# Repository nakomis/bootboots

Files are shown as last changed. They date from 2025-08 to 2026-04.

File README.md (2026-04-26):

# BootBoots - Autonomous Cat Territory Management System

An IoT system using an ESP32-S3 CAM device with AI-powered cat recognition and a humane deterrent mechanism. The system identifies specific cats and can activate deterrents to manage cat territory boundaries.

## Table of Contents

<!-- toc -->

- [Overview](#overview)
- [Architecture Diagram](#architecture-diagram)
- [Components](#components)
  * [Embedded Firmware](#embedded-firmware)
  * [AWS Infrastructure](#aws-infrastructure)
  * [Documentation](#documentation)
  * [Utilities](#utilities)
- [Supported Hardware](#supported-hardware)
  * [Primary: ESP32-S3 WROOM N16R8 CAM](#primary-esp32-s3-wroom-n16r8-cam)
  * [Legacy: ESP32-CAM AI-Thinker](#legacy-esp32-cam-ai-thinker)
- [Project Structure](#project-structure)
- [Quick Start](#quick-start)
  * [Prerequisites](#prerequisites)
  * [Initial Device Setup](#initial-device-setup)
  * [OTA Updates (Preferred)](#ota-updates-preferred)
- [Cat Safety Logic](#cat-safety-logic)
- [Related Projects](#related-projects)
- [License](#license)

<!-- tocstop -->

## Overview

I have four cats. My neighbour also has a cat — Mr Boots — who has worked out that my cat flap is unlocked and that my cats' food bowl is, from his perspective, a free buffet. For a while the solution was shooing him out whenever I spotted him, but he's persistent, fast, and frankly quite smug about the whole thing. So I built this.

Meet the culprit. Boots is a sleek all-black cat with bright green eyes and an expression of complete innocence that frankly cannot be trusted.

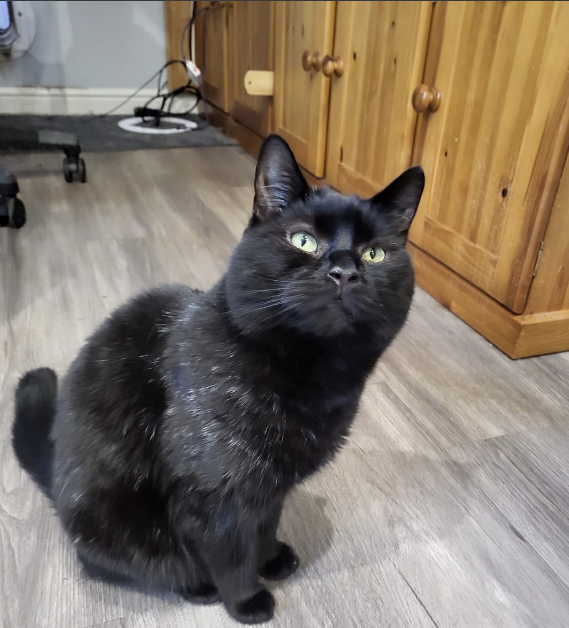
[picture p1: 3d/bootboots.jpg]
Mr Boots
<div align="center"><br/><em>Mr Boots — looking like he's never stolen a meal in his life</em></div>

The system needs to tell Boots apart from my own cats, who are allowed in and must never be on the receiving end of a water mist. Introducing the household:

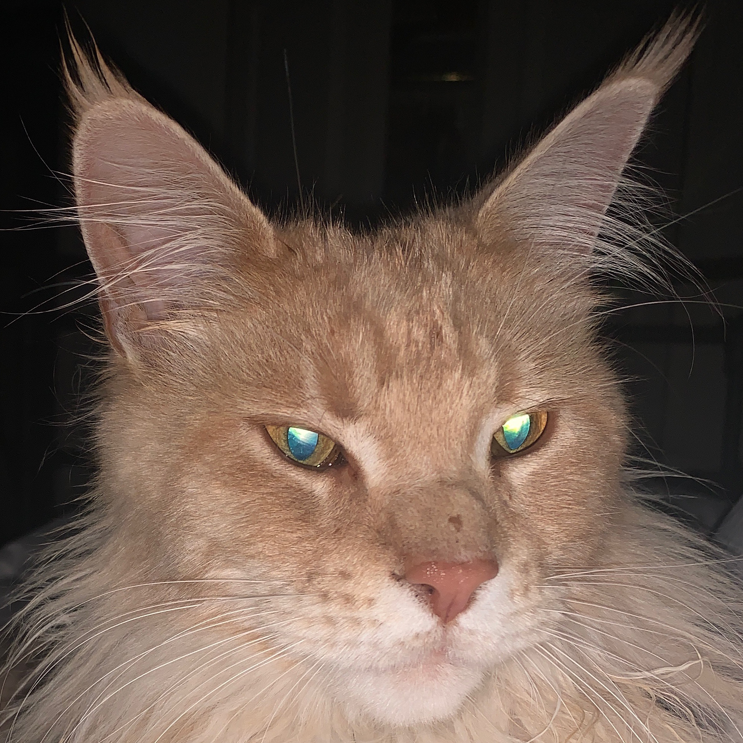
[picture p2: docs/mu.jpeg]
Mu
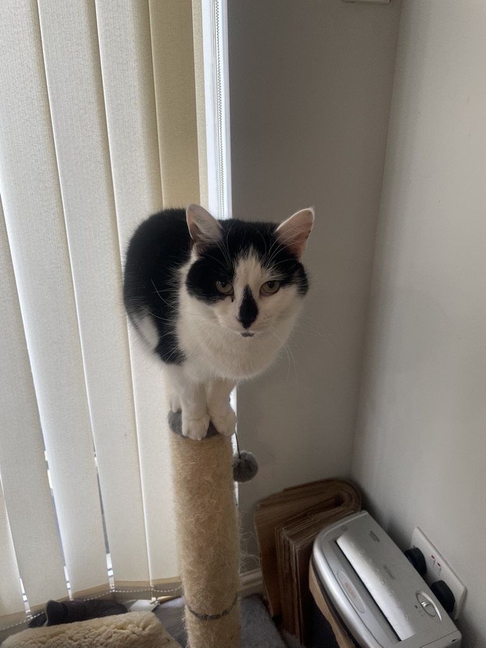
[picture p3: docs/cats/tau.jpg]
Tau
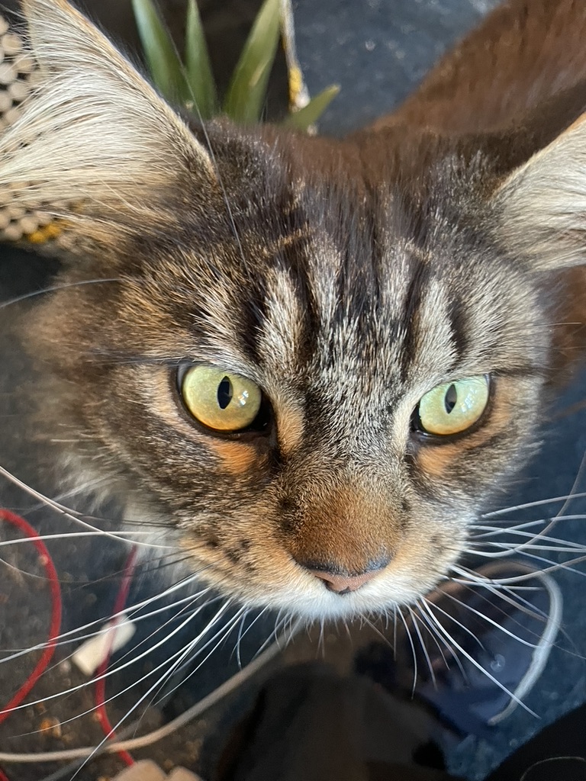
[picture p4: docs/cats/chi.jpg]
Chi
|  |  |  |
|:---:|:---:|:---:|
| **Mu** — Maine Coon; undisputed matriarch of the household and absolutely aware of it | **Tau** — black and white tuxedo; perches in high places and judges everyone | **Chi** — Maine Coon dark tabby; patriarch of the family and apparently very interested in electronics |
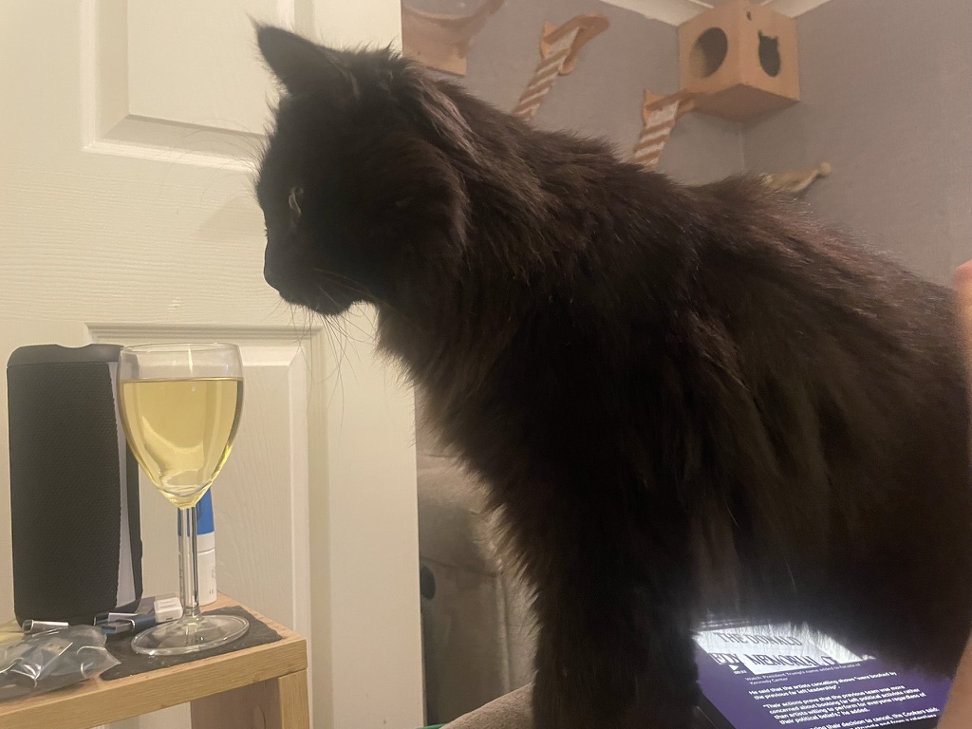
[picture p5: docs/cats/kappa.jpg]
Kappa
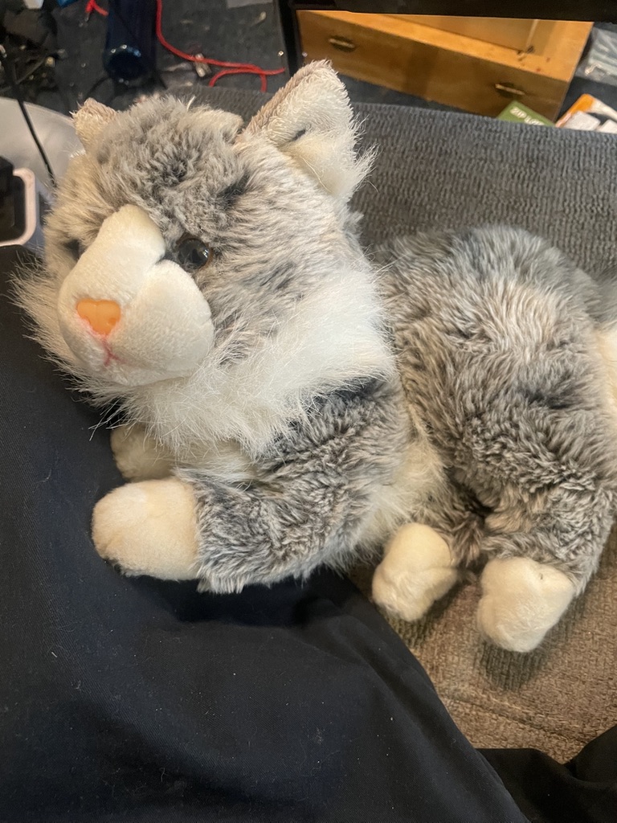
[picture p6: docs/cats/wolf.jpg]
Wolf
|  |  | |
| **Kappa** — Chi and Tau's son; inherited his dad's fur and his mum's attitude | **Wolf** — not a real cat; a stuffed toy pressed into service as a test subject because he's much easier to pose than the others | |

The AI model is a seven-class classifier trained to recognise each cat individually: Boots, Chi, Tau, Kappa, Mu, Wolf (the stuffed-toy test subject), and NoCat (empty frames). At inference time the classification collapses to a binary spray decision — Boots triggers the deterrent; everyone else is safe. The whole pipeline — camera capture, cloud inference via a SageMaker serverless endpoint running EfficientNetV2B1, and a deterrent sequence of LEDs and a short water mist — runs autonomously. Boots has so far remained unimpressed, but the data is promising.

## Architecture Diagram

Deterrence Architecture

## Components

### Embedded Firmware

The [embedded](embedded) directory contains Arduino-based firmware for ESP32 camera devices:

- **[bootloader](embedded/bootloader)** - Factory bootloader that checks for pending OTA updates on every boot. Enables single-partition OTA architecture for maximum firmware space.

- **[catcam](embedded/catcam)** - Main application with camera capture, WiFi, Bluetooth LE, SD card logging, and AI inference integration. Includes 15+ custom libraries:
  - `BluetoothOTA` - Bluetooth-based OTA control
  - `BluetoothService` - Device status monitoring and image transfer via BLE
  - `Camera` - Image capture and PSRAM buffer management
  - `CaptureController` - Capture orchestration
  - `CatCamHttpClient` - HTTPS POST to AWS SageMaker inference API
  - `ImageStorage` - Image file management
  - `InputManager` - Button and input handling
  - `LedController` - RGB LED control
  - `NeoPixel` - WS2812 LED driver
  - `OTAUpdate` - Two-stage OTA update mechanism
  - `PCF8574Manager` - I2C GPIO expander control
  - `SDLogger` - Thread-safe SD card logging with FreeRTOS mutex
  - `SystemManager` - System state management
  - `VideoRecorder` - MJPEG video recording to SD card
  - `WifiConnect` - WiFi connection management

The bootloader-based OTA architecture maximises available flash space by using a single large application partition (7MB on ESP32-S3) instead of the traditional dual-partition approach.

### AI / ML Training

The [local-training](local-training) directory contains the full offline training and deployment pipeline, designed to run on an M-series Mac with Metal GPU acceleration:

- **`download_data_multiclass.py`** — Pulls labelled training images from S3/DynamoDB, organises them into per-cat class directories, and applies an 80/20 training/validation split
- **`train_multiclass.py`** — Trains an EfficientNetV2B1-based seven-class classifier (90.97% validation accuracy; 240×240 input, pipeline augmentation, LR range test support)
- **`predict.py`** — Runs the trained model against individual images or directories for offline evaluation
- **`serve.py`** — Local inference server (localhost:8765) used by the sandbox app to show prediction badges during manual labelling
- **`export_for_sagemaker.py`** — Exports the `.keras` model to TF Serving SavedModel format and packages it as `model.tar.gz`
- **`deploy_model.sh`** — Full deploy pipeline: export → S3 upload → new SageMaker model + endpoint config → live endpoint update

See [local-training/README.md](local-training/README.md) for the full workflow.

### AWS Infrastructure

The [infra](infra) directory contains AWS CDK stacks (TypeScript) for cloud services:

- **IoT Device Stack** - AWS IoT Thing provisioning, certificate generation, and SSM Parameter Store integration
- **API Gateway Stack** - REST API endpoints for device communication
- **AI Training Stack** - SageMaker serverless endpoint (TF Serving 2.16, EfficientNetV2B1), inference Lambda, and API Gateway for camera-to-cloud classification requests
- **Firmware Cleanup Stack** - Lambda function that manages firmware versions in S3, keeping only the 3 most recent versions and auto-updating the manifest

### Documentation

The [docs](docs) directory contains architecture diagrams:

- `architecture/architecture-deterrence.drawio` - Live deterrence system architecture
- `architecture/architecture-training.drawio` - ML training pipeline architecture

SVG versions are auto-generated via pre-commit hook when `.drawio` files change.

### Utilities

The [scripts](scripts) directory contains:

- `install-hooks.sh` - Git hooks installation script

The [githooks](githooks) directory contains git hooks for auto-generating architecture SVGs and TOC updates.

## Supported Hardware

### Primary: ESP32-S3 WROOM N16R8 CAM

| Feature | Specification |
|---|---|
| Chipset | ESP32-S3 (dual-core 240MHz Xtensa LX7) |
| Flash | 16MB (QSPI) |
| PSRAM | 8MB (Octal SPI) |
| Camera | OV5640 (5MP, autofocus) |
| LED | WS2812 RGB addressable (GPIO 48) |
| Storage | microSD card slot |

### Legacy: ESP32-CAM AI-Thinker

| Feature | Specification |
|---|---|
| Flash | 4MB |
| PSRAM | 4MB |
| Camera | OV2640 (2MP) |

## Project Structure

```
bootboots/
├── docs/
│   └── architecture/          # System architecture diagrams (.drawio + .svg)
│
├── embedded/
│   ├── bootloader/            # Factory bootloader (OTA staging)
│   ├── catcam/                # Main camera application
│   │   ├── include/           # Header files
│   │   ├── lib/               # Custom libraries (15+)
│   │   ├── scripts/           # Build and deployment scripts
│   │   └── src/               # Main application source
│   ├── CLAUDE.md              # Detailed technical context
│   └── README.md              # Embedded firmware documentation
│
├── githooks/                  # Git hooks for automation
│
├── infra/                     # AWS CDK infrastructure (TypeScript)
│   ├── lib/                   # CDK stack definitions
│   └── lambda/                # Lambda function code
│
├── local-training/            # Offline ML training pipeline (M-series Mac)
│   ├── download_data_multiclass.py   # Pull labelled images from S3/DynamoDB
│   ├── train_multiclass.py           # Train EfficientNetV2B1 classifier
│   ├── predict.py                    # Offline inference on images
│   ├── serve.py                      # Local inference server (port 8765)
│   ├── export_for_sagemaker.py       # Export to TF Serving format
│   ├── deploy_model.sh               # Full deploy → SageMaker
│   └── README.md                     # Full training workflow
│
├── scripts/                   # Project-wide utility scripts
│
└── README.md                  # This file
```

## Quick Start

### Prerequisites

- Python 3.11 (managed via `asdf`; required for TensorFlow)
- PlatformIO CLI
- Node.js and npm (for infrastructure)
- AWS CLI configured with `nakom.is-sandbox` profile
- draw.io desktop app (for architecture diagram generation)
- githooks installed using `./scripts/install-hooks.sh`

### Initial Device Setup

1. **Generate secrets** from AWS SSM Parameter Store:
   ```bash
   cd embedded/catcam
   export AWS_PROFILE=nakom.is-sandbox
   python3 scripts/generate_secrets.py
   ```

2. **Build and flash** (USB - for factory-new devices):
   ```bash
   cd embedded/catcam
   ./scripts/factory_setup.sh /dev/cu.usbserial-XXXX
   ```

See [embedded/README.md](embedded/README.md) for detailed setup instructions.

### OTA Updates (Preferred)

Once a device is set up, use OTA updates via Bluetooth:

```bash
cd embedded/catcam
export AWS_PROFILE=nakom.is-sandbox
python3 scripts/build_and_upload.py
```

Then use the web interface to push the update to the device via Bluetooth.

## Cat Safety Logic

The deterrence system includes multiple safety layers to prevent false activations:

- **Multiclass classification** — The model identifies each cat individually (Boots, Chi, Tau, Kappa, Mu, Wolf, NoCat) rather than a binary Boots/NotBoots decision, giving greater flexibility in per-cat logic
- **Ultra-safe thresholds** — 90%+ confidence required before triggering the spray
- **Protected cats** — Household cats (Chi, Tau, Kappa, Mu) are hardcoded to never trigger deterrents, regardless of confidence
- **False positive prevention** — Requires 2+ consecutive positive detections
- **Confidence validation** — All non-target classes must show low confidence before acting

## Related Projects

- **[sandboxsite](https://github.com/nakomis/sandboxsite)** - React web interface for OTA updates and device control via Web Bluetooth, plus AWS CDK infrastructure (CloudFront, Cognito, S3)

## License

This project is released under [CC0 1.0 Universal](LICENSE) - public domain dedication.

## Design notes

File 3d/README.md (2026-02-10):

Designed in OnShape

https://cad.onshape.com/documents/f4b5a88bad5686f9d68e4276/w/19fd6644adc7253050f139b0/e/89d52341bea3467f4a4d6d62

For the "No Boots" image on thid lid of the box, I started with the following image:

Mr Boots

I then converted the image to something suitable for 3d printing using an AI image generator [Envanto](https://labs.envato.com/apps/image-gen/) with the following prompt

```
The image should be an svg, black-and-white only (no greyscale), and should be slightly cartoonish. I'll be 3d-printing it on a surface, so it'll can't have too much fine detail. Also please add a circle round it with a bar - in a "No Cats!" style
```

Envanto can only produce scalars, but the resulting .png was very suitable for conversion to 3d

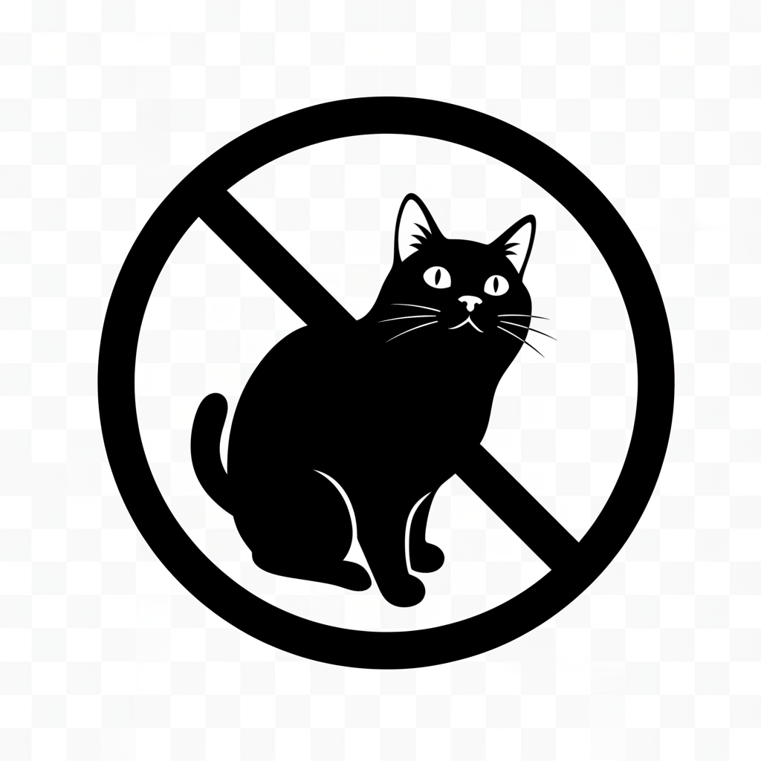
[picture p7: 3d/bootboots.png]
scalar Mr Boots


I then used [imagemagick](https://imagemagick.org/) and [potrace](https://potrace.sourceforge.net/) to convert the image to .svg

```
magick bootboots.png -alpha remove -alpha off -threshold 50%
      bootboots.pbm && potrace bootboots.pbm -s -o bootboots.svg && rm
      bootboots.pbm
```

Once that was done, I then used [OpenSCAD](https://openscad.org/) to convert the svg to a 3d stl

```
linear_extrude(height = 1)
    import("bootboots.svg", center = true);
```

Once I had the stl, I could then import it into [OnShape](https://www.onshape.com/) and apply it to [my model](https://cad.onshape.com/documents/f4b5a88bad5686f9d68e4276/w/19fd6644adc7253050f139b0/e/29b19d4383800b594f26c8da)

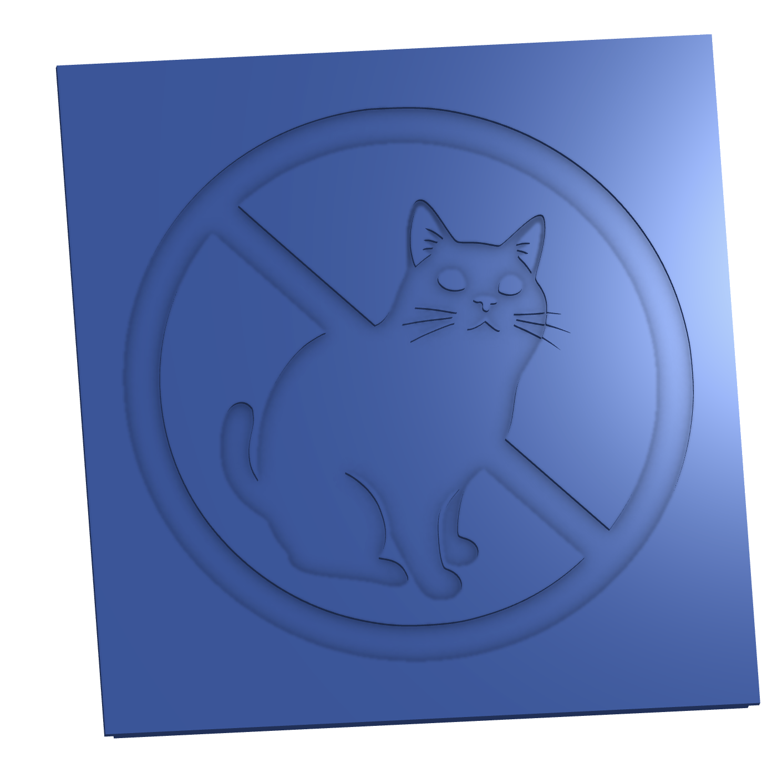
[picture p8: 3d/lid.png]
no Mr Boots


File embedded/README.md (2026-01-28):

# BootBoots ESP32 CatCam Firmware

ESP32-based camera system with bootloader-based OTA updates for maximised flash space.

## Architecture

This project uses a **bootloader-based OTA architecture** that maximises available flash space:

### ESP32-S3 (16MB Flash - Primary Target)
- **Factory Partition** (1MB @ 0x10000): Minimal bootloader that checks for pending OTA updates
- **OTA0 Partition** (7MB @ 0x110000): Main application partition
- **SPIFFS** (~8MB): File system for images and logs
- **SD Card**: Staging area for firmware downloads

### Legacy ESP32-CAM (4MB Flash)
- **Factory Partition** (448KB @ 0x10000): Minimal bootloader
- **OTA0 Partition** (3.56MB @ 0x80000): Main application partition
- **SPIFFS** (40KB): File system for logs

### Boot Sequence

```
Power On / Reboot
    |
    v
ESP32 ROM Bootloader
    |
    v
Factory Bootloader (runs every time)
    |
    v
Check NVS for pending OTA
    |
    v
  Pending? --> Flash from SD --> OTA0 --> Reboot
  No --> Boot directly into OTA0
    |
    v
CatCam App (OTA0)
    |
    v
Set boot partition to factory (for next reboot)
    |
    v
Run normally
```

## Project Structure

```
embedded/
|-- bootloader/              # Factory bootloader
|   |-- src/main.cpp         # Bootloader logic
|   |-- partitions_bootloader.csv      # 4MB partition table
|   |-- partitions_bootloader_s3.csv   # 16MB partition table
|   +-- platformio.ini       # Build configuration
|
|-- catcam/                  # Main application
|   |-- src/main.cpp         # Main application entry
|   |-- include/             # Header files
|   |-- lib/                 # Custom libraries (15+)
|   |   |-- AWSAuth/         # AWS IoT authentication
|   |   |-- BluetoothOTA/    # BLE-based OTA control
|   |   |-- BluetoothService/# Device status monitoring
|   |   |-- Camera/          # Image capture
|   |   |-- CaptureController/# Capture orchestration
|   |   |-- CatCamHttpClient/# HTTPS to SageMaker
|   |   |-- ImageStorage/    # Image file management
|   |   |-- InputManager/    # Button handling
|   |   |-- LedController/   # RGB LED control
|   |   |-- NeoPixel/        # WS2812 driver
|   |   |-- OTAUpdate/       # Two-stage OTA
|   |   |-- PCF8574Manager/  # I2C GPIO expander
|   |   |-- SDLogger/        # Thread-safe logging
|   |   |-- SystemManager/   # System state management
|   |   |-- VideoRecorder/   # MJPEG recording
|   |   +-- WifiConnect/     # WiFi management
|   |-- scripts/
|   |   |-- build_and_upload.py  # Build & upload to S3
|   |   +-- factory_setup.sh     # Factory setup script
|   |-- partitions_custom.csv      # 4MB partition table
|   |-- partitions_custom_s3.csv   # 16MB partition table
|   +-- platformio.ini       # Build configuration
|
|-- CLAUDE.md                # Detailed technical context
+-- README.md                # This file
```

## Setup for Factory-New ESP32

### Prerequisites

- Python 3.8+
- PlatformIO CLI
- AWS CLI configured (for S3 uploads)

### Generate Secrets

Before building the firmware, you need to generate `secrets.h` with WiFi credentials and AWS IoT certificates from AWS Systems Manager Parameter Store:

```bash
cd catcam
export AWS_PROFILE=nakom.is-sandbox
python3 scripts/generate_secrets.py
```

This fetches the following parameters and generates `include/secrets.h`:

| Parameter | Description |
|---|---|
| `/Nakomis/Wifi/SSID` | WiFi network name |
| `/Nakomis/Wifi/Password` | WiFi password |
| `/BootsBoots/BootBootsThing/certPem` | AWS IoT device certificate |
| `/BootsBoots/BootBootsThing/privKey` | AWS IoT private key |
| AWS IoT endpoint | Fetched via `iot:describe_endpoint` API |

The script also reads `AmazonRootCA1.pem` from the catcam directory for the AWS root CA.

**Note**: `secrets.h` is gitignored and should never be committed.

### Quick Setup

Use the automated setup script:

```bash
cd catcam
./scripts/factory_setup.sh /dev/cu.usbserial-XXXX
```

This script will:
1. Build the factory bootloader
2. Build the catcam application
3. Flash bootloader to factory partition
4. Flash catcam app to OTA0 partition
5. Set otadata to point to factory partition

### Manual Setup

If you prefer manual setup:

#### Step 1: Build Both Projects

```bash
# Build bootloader (from embedded directory)
cd bootloader
pio run -e esp32s3cam

# Build catcam app
cd ../catcam
pio run -e esp32s3cam
```

#### Step 2: Flash Both Partitions (ESP32-S3)

```bash
# Put device in download mode (hold BOOT, plug USB into OTG port, release BOOT)
~/.platformio/packages/tool-esptoolpy/esptool.py \
  --chip esp32s3 \
  --port /dev/cu.usbmodem* \
  --baud 921600 \
  write_flash -z --flash_mode dout --flash_freq 80m --flash_size 16MB \
  0x0 ../bootloader/.pio/build/esp32s3cam/bootloader.bin \
  0x8000 ../bootloader/.pio/build/esp32s3cam/partitions.bin \
  0x10000 ../bootloader/.pio/build/esp32s3cam/firmware.bin \
  0x110000 .pio/build/esp32s3cam/firmware.bin
```

#### Step 3: Verify Boot Sequence

```bash
pio device monitor -b 115200
```

You should see:
1. `[BOOTLOADER]` messages from factory partition
2. `[CATCAM] Set boot partition to factory for next reboot`
3. Device running normally

## OTA Updates

### Via Web Interface (Recommended)

1. Build and upload new firmware:
   ```bash
   cd catcam
   AWS_PROFILE=nakom.is-sandbox python scripts/build_and_upload.py --version-type patch
   ```

2. Open web interface at http://localhost:3000/firmware

3. Connect to device via Bluetooth

4. Select new version and click "Update"

5. Monitor progress in web UI

### OTA Update Flow

```
Web UI --> Download firmware from S3 to SD card
    |
    v
Set NVS flag (pending=true, size=<bytes>)
    |
    v
Reboot device
    |
    v
Factory bootloader detects pending OTA
    |
    v
Flash firmware: SD card --> OTA0 partition
    |
    v
Delete firmware file from SD card
    |
    v
Boot into new firmware
```

## Development

### Build Commands

**Standard build (ESP32-S3)**:
```bash
cd catcam
pio run -e esp32s3cam
```

**Build and upload (USB)**:
```bash
pio run -e esp32s3cam --target upload --upload-port /dev/cu.usbmodem*
```

**Build, version bump, and upload to S3**:
```bash
AWS_PROFILE=nakom.is-sandbox python scripts/build_and_upload.py --version-type patch
```

### Version Bumping

```bash
# Patch version (1.0.40 -> 1.0.41)
python scripts/build_and_upload.py --version-type patch

# Minor version (1.0.40 -> 1.1.0)
python scripts/build_and_upload.py --version-type minor

# Major version (1.0.40 -> 2.0.0)
python scripts/build_and_upload.py --version-type major

# Build only (no upload)
python scripts/build_and_upload.py --build-only
```

### Serial Monitoring

```bash
pio device monitor -b 115200
```

### Debugging

**View logs from SD card**:
```bash
# Mount SD card and view recent logs
ls -lt /Volumes/FAT32_Mount/logs/ | head -10
cat /Volumes/FAT32_Mount/logs/<latest_log_file>
```

**Check for pending OTA**:
```bash
# Look for firmware file on SD card
ls -lh /Volumes/FAT32_Mount/firmware_update.bin
```

## Partition Tables

### ESP32-S3 (16MB Flash)

| Partition | Type | Offset | Size | Purpose |
|---|---|---|---|---|
| nvs | data/nvs | 0x9000 | 20KB | Settings storage |
| otadata | data/ota | 0xe000 | 8KB | Boot partition selector |
| **factory** | app/factory | **0x10000** | **1MB** | **Bootloader** |
| **ota_0** | app/ota_0 | **0x110000** | **7MB** | **Main app** |
| spiffs | data/spiffs | 0x810000 | ~8MB | File system |
| coredump | data/coredump | 0xFF0000 | 64KB | Crash dumps |

**Total Flash**: 16MB (ESP32-S3 N16R8)

### Legacy ESP32-CAM (4MB Flash)

| Partition | Type | Offset | Size | Purpose |
|---|---|---|---|---|
| nvs | data/nvs | 0x9000 | 20KB | Settings storage |
| otadata | data/ota | 0xe000 | 8KB | Boot partition selector |
| **factory** | app/factory | **0x10000** | **448KB** | **Bootloader** |
| **ota_0** | app/ota_0 | **0x80000** | **3.56MB** | **Main app** |
| spiffs | data/spiffs | 0x3F0000 | 40KB | File system |
| coredump | data/coredump | 0x3FA000 | 24KB | Crash dumps |

**Total Flash**: 4MB (ESP32-CAM)

## Troubleshooting

### Device stuck in boot loop

**Symptom**: Device keeps rebooting, showing bootloader messages

**Cause**: Corrupted OTA0 partition or NVS flag stuck

**Fix (ESP32-S3)**:
```bash
# Erase OTA0 partition
~/.platformio/packages/tool-esptoolpy/esptool.py \
  --chip esp32s3 --port /dev/cu.usbmodem* \
  erase_region 0x110000 0x700000

# Re-flash catcam app
pio run -e esp32s3cam --target upload --upload-port /dev/cu.usbmodem*
```

### Bootloader not running

**Symptom**: Device boots directly into catcam app, no `[BOOTLOADER]` messages

**Cause**: Missing or corrupted bootloader, or otadata not set correctly

**Fix**: Run factory setup script again

### OTA update fails

**Symptom**: Download completes but device doesn't update

**Check**:
1. Verify firmware file on SD card: `ls /Volumes/FAT32_Mount/firmware_update.bin`
2. Check NVS flags via serial monitor
3. Review SD card logs for error messages

## Technical Details

### Why Bootloader-Based OTA?

Traditional ESP32 OTA requires **two app partitions** of equal size to ping-pong between updates. With 16MB flash:
- Dual partition: 2 x 7MB = 14MB used for redundancy
- Single partition + bootloader: 1MB + 7MB = 8MB, leaving more space for SPIFFS

**Result**: Maximum application size with room for large file storage.

### Boot Partition Management

The catcam app calls `esp_ota_set_boot_partition(factory)` on every boot to ensure the factory bootloader runs first. This solves the chicken-and-egg problem where the ESP32 ROM bootloader would otherwise boot directly into OTA0.

### PCF8574 I/O Expander Pin Map

The PCF8574 uses quasi-bidirectional I/O. Input pins must be written HIGH (weak pull-up) to be readable. Active-low output pins are written HIGH when inactive.

| Pin | Name | Direction | Active | Initial State |
|-----|---|---|---|---|
| P0 | PIR Sensor | Input | HIGH | 1 (HIGH) |
| P1 | Light Sensor | Input | - | 1 (HIGH) |
| P2 | Button | Input | - | 1 (HIGH) |
| P3 | Atomizer | Output | LOW | 1 (HIGH = inactive) |
| P4 | Pressure Sensor | Input | - | 1 (HIGH) |
| P5 | LED Strip 1 | Output | LOW | 1 (HIGH = inactive) |
| P6 | LED Strip 2 | Output | LOW | 1 (HIGH = inactive) |
| P7 | Flash LED | Output | HIGH | 0 (LOW = off) |

`PCF8574_INITIAL_PIN_STATE = 0x7F`

### Memory Usage

- **Bootloader**: Minimal dependencies, ~200KB+ free heap
- **CatCam App**: BLE + WiFi + HTTP active, ~38KB free heap
- **OTA Download**: Happens in catcam app with BLE active
- **OTA Flash**: Happens in bootloader with maximum available heap

## License

CC0 1.0 Universal - Public domain dedication.

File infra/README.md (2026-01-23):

# BootBoots Infrastructure

AWS CDK infrastructure for the BootBoots IoT system.

## Prerequisites

- Node.js and npm/yarn
- AWS CLI configured with `nakom.is-sandbox` profile

## Stacks

### IoT Device Stack
Creates AWS IoT resources for device authentication:
- IoT Thing (`BootBootsThing`)
- Auto-generated certificate stored in SSM Parameter Store
- IAM Role and Policy for device access
- Role Alias for credential provider
- IoT Policy for assuming role with certificate

### Firmware Cleanup Stack
Lambda function that manages firmware versions in S3:
- Triggered by S3 upload events (suffix: `firmware.bin`)
- Keeps only the 3 most recent versions per project
- Auto-updates `manifest.json` with version metadata
- See `lambda/firmware-cleanup/README.md` for details

### Infer Lambda Stack
Lambda function for AI inference (cat recognition).

## Deployment

```bash
# Install dependencies
npm install

# Set AWS profile
export AWS_PROFILE=nakom.is-sandbox

# Deploy all stacks
npx cdk deploy --all

# Or deploy specific stacks
npx cdk deploy IotDeviceStack
npx cdk deploy BootBootsFirmwareCleanupStack
```

## SSM Parameters

After deployment, the following parameters are available in SSM:
- `/BootsBoots/cert_pem` - Device certificate PEM
- `/BootsBoots/priv_key` - Device private key

## Project Structure

```
infra/
|-- lib/                    # CDK stack definitions
|-- lambda/
|   |-- firmware-cleanup/   # Firmware version management Lambda
|   +-- infer-lambda/       # AI inference Lambda
|-- bin/                    # CDK app entry point
+-- cdk.out/                # Synthesized CloudFormation (gitignored)
```

## CDK Commands

* `npm run build`   compile typescript to js
* `npm run watch`   watch for changes and compile
* `npm run test`    perform the jest unit tests
* `npx cdk deploy`  deploy this stack to your default AWS account/region
* `npx cdk diff`    compare deployed stack with current state
* `npx cdk synth`   emits the synthesized CloudFormation template

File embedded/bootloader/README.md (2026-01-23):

# BootBoots Minimal Bootloader (Factory App)

A minimal "factory" application that acts as a bootloader for the BootBoots CatCam ESP32 device.

## Architecture

This bootloader uses a **factory + single OTA partition** approach instead of dual OTA partitions, maximizing available flash space for the main application.

### Partition Layout

```
┌─────────────────────────────────────────────┐
│ Factory (448KB) - Bootloader App            │  0x10000-0x80000
├─────────────────────────────────────────────┤
│ OTA0 (3.56MB) - Main Application            │  0x80000-0x3F0000
├─────────────────────────────────────────────┤
│ SPIFFS (40KB) - Logging                     │  0x3F0000-0x3FA000
├─────────────────────────────────────────────┤
│ Coredump (24KB)                             │  0x3FA000-0x400000
└─────────────────────────────────────────────┘
```

**Comparison to Dual-Partition Approach:**
- **Old (dual partition)**: Two 1.94MB app partitions = 3.8MB total, 95% flash usage
- **New (factory + OTA)**: One 3.56MB app partition = ~61% flash usage, room to grow to ~3.4MB

## How It Works

### Boot Flow

1. **ESP32 boots** → Factory app runs (this bootloader)
2. **Check NVS flag** for pending OTA update:
   - **If NO pending update**: Set OTA0 as boot partition and reboot into main app
   - **If pending update**: Flash firmware from SD card to OTA0, then reboot
3. **Main app runs** (from OTA0 partition)
4. **Main app** sets boot partition back to factory (ensures bootloader runs on next reboot)

### Why Main App Sets Boot Partition to Factory

The ESP32 ROM bootloader doesn't automatically prefer the factory partition when otadata is blank - it boots the first valid app partition. Without intervention, the device would boot directly into OTA0, bypassing this bootloader entirely.

**Solution**: The main app calls `esp_ota_set_boot_partition(factory)` on every boot, ensuring this bootloader always runs first. The bootloader then decides whether to flash a pending update or boot into the main app.

### OTA Update Flow

1. **Main app** (in OTA0) receives OTA command via BLE
2. **Main app** downloads firmware to SD card (`/firmware_update.bin`)
3. **Main app** sets NVS flag `pending=true` and `size=<bytes>`
4. **Main app** reboots
5. **Bootloader** detects pending flag
6. **Bootloader** reads firmware from SD card
7. **Bootloader** flashes to OTA0 partition using ESP-IDF OTA API
8. **Bootloader** clears pending flag
9. **Bootloader** deletes firmware file from SD card
10. **Bootloader** sets OTA0 as boot partition and reboots
11. **New firmware** runs from OTA0

### Safety Features

- **NVS flag cleared before flash**: Prevents boot loops if flash fails
- **File existence checks**: Verifies firmware file on SD before attempting flash
- **Size validation**: Ensures firmware fits in OTA0 partition
- **Error recovery**: Always boots into main app on error
- **LED feedback**: Visual indication of bootloader state

## LED Blink Codes

- **3 quick blinks**: Bootloader starting
- **10 rapid blinks**: OTA update in progress
- **Single blink every second**: Bootloader shows progress during flash
- **5 quick blinks**: OTA update successful
- **Slow blink (1 sec interval)**: Critical error (system halted)

## Building & Flashing

### Quick Setup (Recommended)

Use the automated factory setup script for new devices:

```bash
cd ../catcam
./scripts/factory_setup.sh /dev/cu.usbmodem*
```

This script will:
1. Build both bootloader and catcam app
2. Flash bootloader to factory partition (0x10000)
3. Flash catcam app to OTA0 partition (0x80000)
4. Verify boot sequence

### Manual Flash (via USB)

If you need to flash just the bootloader:

```bash
cd /Users/martinmu_1/repos/nakomis/bootboots/embedded/bootloader
pio run -e esp32s3cam --target upload --upload-port /dev/cu.usbmodem*
```

This flashes the bootloader to the **factory** partition.

**Note**: You must also flash the main catcam app to OTA0 partition for the system to work.

### Building Main Application

The main application (`catcam`) must be built with a partition table that matches:
- OTA0 partition at 0x80000
- Maximum size: 3,604,480 bytes (3.56MB)

Update `catcam/partitions_custom.csv` to match `bootloader/partitions_bootloader.csv`.

### OTA Update Process

1. Main app downloads firmware to SD card
2. Sets NVS: `prefs.putBool("pending", true)` and `prefs.putUInt("size", <bytes>)`
3. Reboots
4. Bootloader handles the rest automatically

## NVS Namespace

The bootloader uses the `"ota"` NVS namespace with:
- **Key**: `pending` (bool) - Whether OTA update is pending
- **Key**: `size` (uint32) - Expected firmware size in bytes

## Dependencies

- **SD_MMC**: SD card access (1-bit mode)
- **Preferences**: NVS (Non-Volatile Storage) for OTA flag
- **esp_ota_ops.h**: ESP-IDF OTA API
- **esp_partition.h**: Partition management

## Serial Output

The bootloader outputs detailed logs via Serial (115200 baud):
- Boot detection
- OTA status
- Flash progress (every 10%)
- Error messages
- Reboot notifications

## File Structure

```
bootloader/
├── platformio.ini              # PlatformIO configuration
├── partitions_bootloader.csv   # Partition table
├── README.md                   # This file
├── include/
│   └── version.h              # Bootloader version
└── src/
    └── main.cpp               # Bootloader implementation
```

## Version

Current Version: **1.0.0**

## Notes

- **Factory partition is PERMANENT**: Once flashed, the factory app stays there forever. Only the main app (OTA0) can be updated via OTA.
- **SD card required**: OTA updates require an SD card to stage firmware files.
- **1-bit SD mode**: Uses 1-bit mode to minimize pin usage.
- **No WiFi/BLE**: Bootloader is minimal - no wireless connectivity, just flash and boot.
- **Fast boot**: If no pending OTA, bootloader boots into main app in ~1 second.

## Troubleshooting

### Bootloader won't flash
- Ensure device is in download mode (GPIO0 pulled low during boot)
- Check USB port matches `upload_port` in `platformio.ini`

### Bootloader boots into main app immediately
- This is normal if no pending OTA update
- Check NVS flag is set correctly by main app

### OTA update fails
- Check SD card is inserted and formatted (FAT32)
- Verify firmware file exists: `/firmware_update.bin`
- Check serial output for detailed error messages
- Ensure firmware size fits in OTA0 partition (3.8MB max)

### Boot loop
- Bootloader clears NVS flag before flashing to prevent boot loops
- If stuck, reflash bootloader via USB
- Check main app sets NVS flag correctly

## License

CC0 1.0 Universal - Public domain dedication.

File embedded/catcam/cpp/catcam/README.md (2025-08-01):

# BootBoots - Autonomous Cat Territory Management System

BootBoots Logo

## 🐱 Project Overview

BootBoots is an intelligent, autonomous cat territory management system built on the ESP32-CAM platform. It uses AI-powered computer vision to identify specific cats and selectively activate deterrent mechanisms to protect designated areas while keeping friendly cats safe.

### Key Features

- **AI-Powered Cat Recognition**: Uses AWS SageMaker for accurate cat identification
- **Selective Deterrent System**: Ultrasonic atomizer activation based on cat identity
- **Ultra-Safe Design**: Multiple validation layers prevent false positives
- **Special Kappa Protection**: Enhanced safety for frequently misidentified cats
- **Comprehensive Logging**: SD card storage with detailed event logs
- **Bluetooth Low Energy**: Remote monitoring and log access
- **Over-The-Air Updates**: Remote firmware and web app updates
- **WiFi Connectivity**: Cloud integration and remote access
- **Real-Time Monitoring**: Web-based dashboard for system status

## 🏗️ System Architecture

### Hardware Components

- **ESP32-CAM**: Main controller with integrated camera
- **Ultrasonic Atomizer**: Deterrent mechanism (PCF8574 controlled)
- **SD Card**: Local logging and image storage
- **WiFi Module**: Cloud connectivity and OTA updates
- **Bluetooth LE**: Local monitoring and diagnostics

### Software Stack

#### ESP32 Firmware
- **Platform**: ESP32 Arduino Framework with PlatformIO
- **Language**: C++17
- **Libraries**: 
  - ESP32-CAM for image capture
  - ArduinoJson for data serialization
  - ESP32 BLE Arduino for Bluetooth
  - ArduinoOTA for wireless updates
  - ESPmDNS for network discovery

#### Web Application
- **Framework**: React with TypeScript
- **UI Library**: Material-UI
- **Authentication**: AWS Cognito
- **Bluetooth**: Web Bluetooth API
- **Updates**: Service Worker with OTA support

## 🔧 Installation & Setup

### Prerequisites

- PlatformIO IDE or Arduino IDE with ESP32 support
- Node.js 16+ and npm
- AWS Account (for SageMaker integration)
- ESP32-CAM development board

### ESP32 Firmware Setup

1. **Clone the Repository**
   ```bash
   git clone <repository-url>
   cd bootboots/embedded/catcam/cpp/catcam
   ```

2. **Install PlatformIO**
   ```bash
   pip install platformio
   ```

3. **Configure Secrets**
   ```bash
   cp include/secrets.h.template include/secrets.h
   ```
   
   Edit `include/secrets.h` with your credentials:
   ```cpp
   // WiFi Configuration
   const char* const WIFI_SSID = "your-wifi-network";
   const char* const WIFI_PASSWORD = "your-wifi-password";
   
   // API Configuration
   const char* const API_URL = "https://your-sagemaker-endpoint.amazonaws.com/invocations";
   const char* const API_KEY = "your-api-key-here";
   
   // OTA Update Configuration
   const char* const OTA_PASSWORD = "your-secure-ota-password";
   ```

4. **Build and Upload**
   ```bash
   pio run --target upload
   ```

### Web Application Setup

1. **Navigate to Web App Directory**
   ```bash
   cd /path/to/sandboxsite/sandbox-app
   ```

2. **Install Dependencies**
   ```bash
   npm install
   ```

3. **Start Development Server**
   ```bash
   npm start
   ```

4. **Access Application**
   - Local: http://localhost:3000
   - Production: https://sandbox.nakomis.com

## 🤖 AI Cat Recognition System

### Supported Cats

The system recognizes 6 specific cats with unique behavioral profiles:

| Index | Cat Name | Special Notes |
|---|---|---|
| 0 | Boots | Standard detection |
| 1 | Chi | Standard detection |
| 2 | **Kappa** | **Protected** - Enhanced safety due to 67% misidentification rate |
| 3 | Mu | Standard detection |
| 4 | Tau | Standard detection |
| 5 | Wolf | Standard detection |

### Safety Thresholds

- **Minimum Confidence**: 85% for deterrent activation
- **Kappa Protection**: 95% confidence required + additional validation
- **Cooldown Period**: 30 seconds between activations
- **False Positive Prevention**: Multiple validation layers

### Detection Process

1. **Image Capture**: ESP32-CAM captures high-resolution image
2. **AI Analysis**: Image sent to AWS SageMaker endpoint
3. **Confidence Evaluation**: Multiple threshold checks
4. **Safety Validation**: Special Kappa protection logic
5. **Action Decision**: Deterrent activation or safe passage
6. **Logging**: Complete event logging to SD card

## 🔄 Over-The-Air (OTA) Update System

### ESP32 OTA Updates

#### Features
- **Password Protection**: Secure updates with configurable password
- **Network Discovery**: Available as "BootBoots-CatCam.local"
- **Safety Integration**: Automatically disables deterrent during updates
- **Progress Tracking**: Real-time update status via Bluetooth
- **Error Recovery**: Comprehensive error handling and logging

#### Deployment Process

1. **Prepare New Firmware**
   ```bash
   cd bootboots/embedded/catcam/cpp/catcam
   # Make your code changes
   pio run  # Verify build succeeds
   ```

2. **Deploy via PlatformIO**
   ```bash
   # Option 1: Command line OTA upload
   pio run --target upload --upload-port BootBoots-CatCam.local
   
   # Option 2: Use PlatformIO IDE
   # 1. Open PlatformIO IDE
   # 2. Click "Upload" dropdown
   # 3. Select "Upload via Network"
   # 4. Choose "BootBoots-CatCam" from device list
   # 5. Enter OTA password when prompted
   ```

3. **Deploy via Arduino IDE**
   ```bash
   # 1. Open Arduino IDE
   # 2. Go to Tools > Port
   # 3. Select "BootBoots-CatCam at <IP address>"
   # 4. Click Upload
   # 5. Enter OTA password when prompted
   ```

#### OTA Security

- **Password Authentication**: Configurable in `secrets.h`
- **Network Encryption**: WPA2/WPA3 WiFi security
- **mDNS Discovery**: Secure local network discovery
- **Update Validation**: Firmware signature verification

### Web Application OTA Updates

#### Features
- **Service Worker**: Background update detection
- **Automatic Checks**: Every 30 minutes
- **Manual Updates**: User-initiated update checks
- **Progressive Enhancement**: Works offline with cached resources
- **Safe Rollback**: Automatic fallback on update failure
- **S3 + CloudFront**: AWS-hosted with global CDN distribution

#### Deployment Process

**Your Setup**: AWS CDK with S3 bucket + CloudFront distribution

1. **Update Version Number**
   ```bash
   cd sandboxsite/sandbox-app
   # Update version in package.json
   npm version patch  # or minor/major
   ```

2. **Build Production Version**
   ```bash
   npm run build
   # Creates optimized build in ./build/ directory
   ```

3. **Deploy to S3 Bucket**
   ```bash
   # Get your S3 bucket name from CDK stack
   aws cloudformation describe-stacks --stack-name SandboxCloudfrontStack \
     --query 'Stacks[0].Outputs[?OutputKey==`BucketName`].OutputValue' --output text
   
   # Sync build files to S3 (replace BUCKET_NAME with actual bucket)
   aws s3 sync ./build/ s3://BUCKET_NAME --delete
   
   # Set proper cache headers for static assets
   aws s3 cp ./build/static/ s3://BUCKET_NAME/static/ --recursive \
     --cache-control "max-age=31536000" --metadata-directive REPLACE
   
   # Set short cache for index.html to enable quick updates
   aws s3 cp ./build/index.html s3://BUCKET_NAME/index.html \
     --cache-control "max-age=300" --metadata-directive REPLACE
   ```

4. **Invalidate CloudFront Cache**
   ```bash
   # Get CloudFront distribution ID
   aws cloudformation describe-stacks --stack-name SandboxCloudfrontStack \
     --query 'Stacks[0].Outputs[?OutputKey==`DistributionId`].OutputValue' --output text
   
   # Create invalidation (replace DISTRIBUTION_ID with actual ID)
   aws cloudfront create-invalidation --distribution-id DISTRIBUTION_ID \
     --paths "/*"
   ```

5. **Automated Deployment Script**
   Create `deploy.sh` in `sandbox-app/` directory:
   ```bash
   #!/bin/bash
   set -e
   
   echo "🚀 Starting BootBoots Web App Deployment..."
   
   # Get current version
   CURRENT_VERSION=$(node -p "require('./package.json').version")
   echo "📦 Current version: $CURRENT_VERSION"
   
   # Build production version
   echo "🔨 Building production version..."
   npm run build
   
   # Get AWS resources from CloudFormation
   BUCKET_NAME=$(aws cloudformation describe-stacks --stack-name SandboxCloudfrontStack \
     --query 'Stacks[0].Outputs[?OutputKey==`BucketName`].OutputValue' --output text)
   DISTRIBUTION_ID=$(aws cloudformation describe-stacks --stack-name SandboxCloudfrontStack \
     --query 'Stacks[0].Outputs[?OutputKey==`DistributionId`].OutputValue' --output text)
   
   echo "📡 Deploying to S3 bucket: $BUCKET_NAME"
   
   # Sync files to S3
   aws s3 sync ./build/ s3://$BUCKET_NAME --delete
   
   # Set cache headers
   aws s3 cp ./build/static/ s3://$BUCKET_NAME/static/ --recursive \
     --cache-control "max-age=31536000" --metadata-directive REPLACE
   aws s3 cp ./build/index.html s3://$BUCKET_NAME/index.html \
     --cache-control "max-age=300" --metadata-directive REPLACE
   
   # Invalidate CloudFront
   echo "🌐 Invalidating CloudFront distribution: $DISTRIBUTION_ID"
   aws cloudfront create-invalidation --distribution-id $DISTRIBUTION_ID --paths "/*"
   
   echo "✅ Deployment complete! Version $CURRENT_VERSION is now live."
   echo "🔗 URL: https://sandbox.nakomis.com"
   ```

   Make it executable and run:
   ```bash
   chmod +x deploy.sh
   ./deploy.sh
   ```

#### Versioning Strategy

**Semantic Versioning**: Use `package.json` version field
- **Patch** (1.0.1): Bug fixes, minor updates
- **Minor** (1.1.0): New features, OTA updates
- **Major** (2.0.0): Breaking changes

**Service Worker Versioning**:
```javascript
// In public/sw.js
const CACHE_NAME = 'bootboots-v' + process.env.REACT_APP_VERSION;
```

**Environment Variables**:
```bash
# Add to .env file
REACT_APP_VERSION=$npm_package_version
```

**Automatic Version Detection**:
```typescript
// In OTAUpdate.tsx
const currentVersion = process.env.REACT_APP_VERSION || '1.0.0';
```

#### Update Process
- Service worker detects new version via cache name change
- User sees update notification in OTA Updates tab
- One-click installation with automatic reload
- CloudFront ensures global distribution
- S3 versioning provides rollback capability

## 📊 System Monitoring

### Bluetooth Integration

The system provides comprehensive monitoring via Bluetooth Low Energy:

#### Available Services
- **System Status**: Real-time operational data
- **Log Access**: Recent SD card log entries
- **Update Status**: OTA update progress and status
- **Configuration**: Runtime parameter adjustment

#### Connection Process
1. Open web application
2. Navigate to "Bluetooth" tab
3. Click "Connect to BootBoots"
4. Select device from browser dialog
5. Monitor real-time system status

### Logging System

#### Log Categories
- **INFO**: Normal operations and status updates
- **WARN**: Non-critical issues and warnings
- **ERROR**: System errors and failures
- **CRITICAL**: Severe issues requiring attention

#### Log Storage
- **Primary**: SD card with rotation
- **Secondary**: Serial output for debugging
- **Remote**: Bluetooth access for monitoring

## 🔒 Security Features

### Authentication & Authorization
- **Web App**: AWS Cognito integration
- **ESP32 OTA**: Password-protected updates
- **Bluetooth**: Secure pairing and encryption

### Safety Systems
- **Multi-Layer Validation**: Prevents false positive activations
- **Kappa Protection**: Enhanced safety for misidentified cats
- **System Monitoring**: Continuous health checks
- **Emergency Shutdown**: Manual and automatic safety stops

### Network Security
- **WPA2/WPA3**: Secure WiFi connectivity
- **HTTPS**: Encrypted web communications
- **mDNS**: Secure local network discovery

## 🛠️ Development

### Project Structure

```
bootboots/embedded/catcam/cpp/catcam/
├── src/
│   └── main.cpp                 # Main application logic
├── lib/
│   ├── Atomizer/               # Deterrent control
│   ├── BluetoothService/       # BLE communication
│   ├── Camera/                 # ESP32-CAM integration
│   ├── HttpClient/             # API communication
│   ├── MessageQueue/           # Event handling
│   ├── NamedImage/             # Image data structures
│   ├── OTAUpdate/              # Over-the-air updates
│   ├── PCF8574Manager/         # I2C GPIO expansion
│   ├── SDLogger/               # Logging system
│   └── WifiConnect/            # WiFi management
├── include/
│   ├── SystemState.h           # Shared system state
│   └── secrets.h.template      # Configuration template
└── platformio.ini              # Build configuration
```

### Building from Source

1. **Install Dependencies**
   ```bash
   pio lib install
   ```

2. **Build Firmware**
   ```bash
   pio run
   ```

3. **Run Tests**
   ```bash
   pio test
   ```

4. **Upload to Device**
   ```bash
   pio run --target upload
   ```

### Memory Usage

Current build statistics:
- **RAM Usage**: 21.3% (69,808 / 327,680 bytes)
- **Flash Usage**: 62.9% (1,977,777 / 3,145,728 bytes)
- **Build Time**: ~28 seconds

## 📈 Performance Metrics

### System Specifications
- **Detection Latency**: <2 seconds from image capture to decision
- **WiFi Range**: 50+ meters (depending on environment)
- **Battery Life**: N/A (powered system)
- **Storage Capacity**: Limited by SD card size
- **Concurrent Connections**: 1 Bluetooth, unlimited web clients

### Reliability Features
- **Watchdog Timer**: Automatic system recovery
- **Error Recovery**: Graceful failure handling
- **Health Monitoring**: Continuous system checks
- **Redundant Logging**: Multiple log destinations

## 🐛 Troubleshooting

### Common Issues

#### Build Errors
```bash
# Clean build environment
pio run --target clean
pio run

# Update libraries
pio lib update
```

#### WiFi Connection Issues
- Verify credentials in `secrets.h`
- Check network signal strength
- Ensure WPA2/WPA3 compatibility

#### OTA Update Failures
- Verify OTA password
- Check network connectivity
- Ensure sufficient flash memory
- Monitor serial output for errors

#### Bluetooth Connection Problems
- Clear browser Bluetooth cache
- Restart ESP32 device
- Check Web Bluetooth API support

### Debug Mode

Enable verbose logging:
```cpp
// In main.cpp
#define DEBUG_MODE 1
```

### Serial Monitoring
```bash
pio device monitor
```

## 🤝 Contributing

### Development Guidelines
1. Follow C++17 standards
2. Use consistent naming conventions
3. Add comprehensive comments
4. Include unit tests for new features
5. Update documentation

### Pull Request Process
1. Fork the repository
2. Create feature branch
3. Implement changes with tests
4. Update documentation
5. Submit pull request

## 📄 License

This project is licensed under the MIT License - see the LICENSE file for details.

## 🙏 Acknowledgments

- **AWS SageMaker**: AI/ML model hosting
- **ESP32 Community**: Hardware and software support
- **React Community**: Web application framework
- **PlatformIO**: Development environment

## 📞 Support

For support and questions:
- **Issues**: GitHub Issues tracker
- **Documentation**: This README and inline comments
- **Community**: Project discussions

---

**BootBoots** - Keeping your territory safe, one cat at a time! 🐱🛡️

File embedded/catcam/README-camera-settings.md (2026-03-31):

# Camera Settings Reference

## Baseline — Night (with LED strips)

Good starting point for low-light indoor captures with LED strip illumination.

### Resolution & Quality

| Setting | Value |
|---|---|
| Frame Size | UXGA (1600×1200) |
| JPEG Quality | 10 |
| Frame Buffers | 2 |

### Image Quality

| Setting | Value |
|---|---|
| Brightness | 0 |
| Contrast | 1 |
| Saturation | 0 |
| Special Effect | None |

### White Balance

| Setting | Value |
|---|---|
| White Balance | On |
| AWB Gain | On |
| WB Mode | Auto |

### Exposure

| Setting | Value |
|---|---|
| Auto Exposure | Off |
| AEC DSP | On |
| AE Level | 2 |
| AEC Value | 1200 |

> Auto Exposure is disabled and AEC Value set to maximum (1200) to get the longest possible
> exposure in a dark scene. AEC DSP (night mode) is kept on for additional DSP processing.

### Gain

| Setting | Value |
|---|---|
| Auto Gain | On |
| AGC Gain | 5 |
| Gain Ceiling | 6 |

### Corrections

| Setting | Value |
|---|---|
| Bad Pixel Correction | On |
| White Pixel Correction | On |
| Gamma Correction | On |
| Lens Correction | On |
| Downsize Enable | On |

### Orientation

| Setting | Value |
|---|---|
| Horizontal Mirror | Off |
| Vertical Flip | On |

### Test

| Setting | Value |
|---|---|
| Color Bar | Off |

### Flash

| Setting | Value |
|---|---|
| LED Delay (millis) | 1000 |

> 1000ms gives the AEC time to converge after the LED stabilises before the frame is captured.

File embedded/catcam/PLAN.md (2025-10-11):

# PCF8574 and Component Integration Plan

## Overview
Rebuild the BootBoots catcam project incrementally by bringing in components from old.catcam one at a time, starting with PCF8574 I2C GPIO expansion. This approach ensures each component works before adding complexity.

## Key Technical Constraints Identified

### Pin Configuration (ESP32-CAM)
- **I2C (PCF8574)**: GPIO1 (UART0 TX/SDA) + GPIO3 (UART0 RX/SCL)
  - ⚠️ **Critical**: Must disconnect during USB flashing (conflicts with serial)
  - Cannot use Serial Monitor (UART0) after PCF8574 is connected
  - Must use alternative debug output or BLE for monitoring
- **Camera**: Uses pins 0,5,18,19,21,22,23,25,26,27 (already constrained)
- **SD Card**: Uses SD_MMC pins (already in use)
- **Available for future**: GPIO16 mentioned as potentially usable

### Current Working State
✅ **Working**: OTA updates, BLE services, SD logging, WiFi
❌ **Missing**: PCF8574, Camera, Atomizer, HTTP Client, AI integration

## Phase 1: PCF8574 Manager (Foundation for Pin Expansion) ✅ CODE COMPLETE

### 1.1 Copy PCF8574Manager Library ✅
**Files copied**:
- `old.catcam/lib/PCF8574Manager/` → `catcam/lib/PCF8574Manager/` ✓

**Features**:
- I2C GPIO expansion (8 pins: P0-P7)
- Safety features: emergency shutdown, error tracking, self-test
- Pin assignments from old project:
  - P0: Atomizer control
  - P1: Flash LED ← **Currently blinking in test loop**
  - P2: Pressure sensor input
  - P3-P7: Spare (future expansion)

### 1.2 Update Dependencies ✅
**platformio.ini**:
- Already has `Wire` library ✓
- I2C speed: 100kHz for reliability ✓

### 1.3 Integrate into Main ✅
**src/main.cpp   difications** (COMPLETED):
- ✅ Added `#include <Wire.h>` and `#include "PCF8574Manager.h"`
- ✅ Added global: `PCF8574Manager* pcfManager = nullptr;`
- ✅ Added pin definitions: I2C_SDA (GPIO1), I2C_SCL (GPIO3), PCF8574_ADDRESS (0x20)
- ✅ Updated `initializeHardware()`:
  - **Enable internal pull-ups** on GPIO1/GPIO3 using `pinMode(pin, INPUT_PULLUP)`
  - Initialize I2C on GPIO1/GPIO3 at 100kHz
  - No external pull-up resistors needed! ✅
- ✅ Updated `initializeComponents()`: Initialize PCF8574 at address 0x20 with self-test
- ✅ Updated `SystemState.h`: Added `bool pcf8574Ready = false;`
- ✅ Updated system status log: Added PCF8574 status display

### 1.4 Create Simple Test ✅
**Test code integrated** (main.cpp loop()):
- ✅ Initialize PCF8574 with self-test
- ✅ Blink LED on P1 (Flash LED pin) every 2 seconds
- ✅ Log blink state via SDLogger (debug level)
- ✅ Verify via BLE status messages (Serial won't work with PCF8574 connected)
- ⚠️ **CRITICAL**: Must disconnect PCF8574 wiring from GPIO1/GPIO3 before flashing firmware

**Build Status**: ✅ **SUCCESS** (54.4% flash, 20.0% RAM)

### 1.5 Documentation ✅
- ✅ Created `PCF8574_TESTING.md` with complete testing guide
- ✅ Documented pin conflict (GPIO1/GPIO3 = UART0)
- ✅ Documented flashing procedure (disconnect before flash, reconnect after)
- ✅ Created wiring diagram
- ✅ Added troubleshooting section
- ✅ Updated PLAN.md with Phase 1 completion status

### 1.6 Current Status: **READY FOR HARDWARE TESTING** ⏳

**Next Steps**:
1. **Upload firmware to S3** (build and upload):
   ```bash
   python scripts/build_and_upload.py --version-type patch
   ```
2. **Wire PCF8574** according to PCF8574_TESTING.md:
   - Connect SDA to GPIO1, SCL to GPIO3
   - Connect power (3.3V) and ground
   - Set address pins (A0, A1, A2 all to GND = address 0x20)
   - **No external pull-up resistors needed** - internal pull-ups enabled automatically ✅
3. **Deploy firmware via OTA** (web interface → Firmware Manager → Deploy)
   - No need to disconnect PCF8574! OTA works wirelessly ✅
4. **Verify via web interface**:
   - Bluetooth tab → Connect to device
   - Check system status for "PCF8574: OK"
   - Click "Retrieve Logs" → Search for "PCF8574" initialization messages
   - All debugging via web interface - no need to remove SD card! ✅
5. **Visual test**: LED on P1 should blink every 2 seconds
6. **Update PLAN.md**: Mark Phase 1 as fully tested ✓

**Note**: Only disconnect PCF8574 for initial USB serial flash if OTA not yet available.

## Phase 2: Camera Module

### 2.1 Copy Camera Library
**Files to copy**:
- `old.catcam/lib/Camera/` → `catcam/lib/Camera/`
- `old.catcam/lib/NamedImage/` → `catcam/lib/NamedImage/` (dependency)

**Features**:
- ESP32-CAM image capture
- PSRAM buffer management
- Image buffer lifecycle (acquire/release)

### 2.2 Test Camera Independently
- Initialize camera with AI_THINKER pin configuration
- Capture test image
- Save to SD card: `/test_image_N.jpg`
- Verify image size and PSRAM usage
- Monitor via BLE status updates

### 2.3 Integration Points
- Add camera pointer to main.cpp
- Initialize after WiFi/BLE
- Add camera status to SystemState

## Phase 3: Flash LED Control (via PCF8574)

### 3.1 Test Flash LED
- Control PCF8574 P1 (Flash LED pin)
- Create simple blink pattern
- Coordinate with camera capture (flash during photo)

### 3.2 Safety Considerations
- Ensure flash doesn't interfere with camera capture timing
- Add flash enable/disable control

## Phase 4: HTTP Client for AI Integration

### 4.1 Copy HTTP Client
**Files to copy**:
- `old.catcam/lib/CatCamHttpClient/` → `catcam/lib/CatCamHttpClient/`
- `old.catcam/lib/AWSAuth/` → `catcam/lib/AWSAuth/` (if needed)

**Features**:
- HTTPS POST to AWS SageMaker
- SSL/TLS with certificate
- PSRAM optimization for memory

### 4.2 Test HTTP Client
- Create test endpoint or use existing API
- Send dummy image data
- Parse JSON response
- Verify memory usage (critical for ESP32-CAM)

### 4.3 Update Dependencies
**platformio.ini**:
- Already has `WiFiClientSecure` ✓
- Already has `ArduinoHttpClient` ✓
- Already has `ArduinoJson` ✓

## Phase 5: Atomizer Control (Deterrent System)

### 5.1 Copy Atomizer Library
**Files to copy**:
- `old.catcam/lib/Atomizer/` → `catcam/lib/Atomizer/`

**Features**:
- Ultra-safe activation logic
- Multi-layer validation for Kappa protection
- Confidence thresholds (90% Boots, <15% others)
- Cooldown period (60s)
- Consecutive detection requirement (2x)

### 5.2 Wire Atomizer via PCF8574
- Connect atomizer relay to PCF8574 P0
- Test activation via `pcfManager->setAtomizerState(true)`
- Verify safety shutdown works
- Test emergency stop

### 5.3 Integration
- Link Atomizer to PCF8574Manager
- Add atomizer control commands via BLE
- Test manual activation/deactivation from web interface

## Phase 6: Complete AI Detection Loop

### 6.1 Message Queue (Optional)
**Files to copy**:
- `old.catcam/lib/MessageQueue/` → `catcam/lib/MessageQueue/`
- Only if needed for async processing

### 6.2 Integrate Full Detection Pipeline
**Main loop flow**:
1. Capture image (Camera)
2. Send to AI service (HTTP Client)
3. Parse detection result (JSON)
4. Evaluate safety thresholds (Atomizer)
5. Activate deterrent if safe (PCF8574)
6. Log all events (SD Logger) ✓
7. Report via BLE (Bluetooth) ✓

### 6.3 Cat Recognition Setup
**From old project**:
- 6 cats: Boots(0), Chi(1), Kappa(2), Mu(3), Tau(4), Wolf(5)
- Boots = target (index 0)
- Kappa = protected (index 2, 67% misidentification rate)
- Thresholds:
  - Min 85% confidence for any detection
  - Min 90% for Boots activation
  - Max 15% for other cats when activating for Boots
  - Special: NEVER activate if detected cat index == 2 (Kappa hardcoded block)

## Phase 7: Testing & Refinement

### 7.1 End-to-End Test
- Complete detection cycle: camera → AI → decision → atomizer
- Test all cat scenarios (especially Kappa protection)
- Verify false positive prevention
- Monitor memory usage throughout cycle

### 7.2 Safety Validation
- Test PCF8574 emergency shutdown
- Verify atomizer cooldown works
- Test consecutive detection requirement
- Validate Kappa protection (index 2 hardcoded block)

### 7.3 Production Readiness
- Long-running stability test (24h+)
- Memory leak detection
- WiFi reconnection handling
- SD card full handling
- Create deployment checklist

## Critical Notes & Gotchas

### 🔴 PCF8574 Pin Conflict & Flashing
1. **OTA Updates (Recommended)**: ✅ No disconnection needed - flash wirelessly!
2. **USB Serial Flashing Only**: ⚠️ Physically disconnect PCF8574 from GPIO1/GPIO3 before flashing
3. **After USB Flash**: Reconnect PCF8574 to GPIO1/GPIO3 and power cycle
4. **Serial Monitor**: Cannot use after PCF8574 connected (GPIO1/GPIO3 pin conflict)
5. **Debugging**: Use BLE status messages and SD logging only
6. **Future Updates**: Always use OTA once PCF8574 is wired!

### ⚠️ Memory Constraints
- ESP32-CAM: Limited RAM (~38KB free with BLE active)
- Must use PSRAM for camera buffers
- HTTP client uses ~10KB
- BLE uses ~15-20KB
- Leave ~10KB safety margin

### 🛡️ Safety Features (Critical)
- Kappa protection: Hardcoded index check (never activate if index == 2)
- Multi-layer validation: confidence + other cats + consecutive detections
- Emergency shutdown: PCF8574 can force all outputs LOW
- Cooldown enforcement: 60s minimum between activations

### 📋 Testing Order Rationale
1. **PCF8574 first**: Foundation for all I/O expansion
2. **Camera second**: Image capture capability
3. **Flash LED third**: Simple PCF8574 control test
4. **HTTP fourth**: AI communication (complex)
5. **Atomizer fifth**: Safety-critical, test thoroughly
6. **Full integration last**: Complete detection loop

## Success Criteria

**Phase 1 (PCF8574)**:
- [ ] PCF8574 initializes successfully
- [ ] Self-test passes
- [ ] Can control all 8 pins
- [ ] Emergency shutdown works
- [ ] BLE reports status correctly

**Phase 2 (Camera)**:
- [ ] Camera initializes
- [ ] Can capture images
- [ ] Images save to SD card
- [ ] PSRAM usage monitored
- [ ] No memory leaks

**Phase 3-6 (Integration)**:
- [ ] Full detection cycle works
- [ ] AI responses parsed correctly
- [ ] Atomizer activates for Boots (when safe)
- [ ] Kappa NEVER triggers atomizer
- [ ] All events logged to SD

**Phase 7 (Production)**:
- [ ] 24h+ stability test passes
- [ ] No memory leaks detected
- [ ] All safety features validated
- [ ] False positive rate acceptable
- [ ] Complete documentation

## Current Status

**Last Updated**: 2025-10-11 (Phase 1 Code Complete)

### ✅ Completed Infrastructure
- Bootloader + OTA system (factory + OTA0 partitions)
- Firmware cleanup Lambda (keeps 3 most recent versions in S3)
- BLE services (status + OTA commands)
- SD card logging with chunked transfer
- WiFi connectivity
- Web interface firmware manager
- **PCF8574 Manager integration** (code complete, ready for hardware testing)

### 🔄 In Progress
- **Phase 1: PCF8574 Manager - Hardware Testing** ⏳
  - Code complete ✅
  - Build successful ✅
  - Documentation complete ✅
  - **Awaiting hardware test**: Flash firmware, wire PCF8574, verify LED blink

### ⏳ Pending
- Phase 2: Camera Module
- Phase 3: Flash LED Control
- Phase 4: HTTP Client for AI
- Phase 5: Atomizer Control
- Phase 6: Complete AI Detection Loop
- Phase 7: Testing & Refinement

## Next Steps
1. **Hardware Test Phase 1**:
   - Upload firmware to S3: `python scripts/build_and_upload.py --version-type patch`
   - Wire PCF8574 (no external pull-ups needed - internal pull-ups enabled automatically)
   - Deploy firmware via OTA (web interface → Firmware Manager)
     - **No disconnection needed!** OTA works wirelessly ✅
   - Verify via web interface (Bluetooth tab):
     - Check status for "PCF8574: OK"
     - Retrieve logs and search for "PCF8574" initialization
     - **No need to remove SD card!** All logs via web interface ✅
   - Visual test: LED on P1 blinks every 2 seconds
2. **After Phase 1 Success**:
   - Update PLAN.md with hardware test results
   - Remove/comment out LED blink test in loop()
   - Proceed to Phase 2: Camera Module integration

**Note**: The pin conflict only affects USB serial flashing, not OTA updates!

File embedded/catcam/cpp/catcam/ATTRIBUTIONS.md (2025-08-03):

# ATTRIBUTIONS

This file lists all third-party dependencies used in the BootBoots ESP32-CAM firmware project.

## Embedded Firmware Dependencies

### ESP32 Arduino Core
- **License**: LGPL-2.1 and GPL-2.0
- **Source**: https://github.com/espressif/arduino-esp32
- **Description**: Core Arduino functionality for ESP32 microcontrollers

### ESP32 Camera Driver
- **Package**: espressif/esp32-camera
- **Version**: 2.0.4
- **License**: Apache-2.0
- **Source**: https://github.com/espressif/esp32-camera
- **Description**: ESP32 camera driver for OV2640, OV3660, OV5640, and other camera modules

### ArduinoJson
- **Package**: bblanchon/ArduinoJson
- **Version**: 6.21.3
- **License**: MIT
- **Source**: https://github.com/bblanchon/ArduinoJson
- **Description**: JSON library for Arduino and embedded C++

### ESP32 BLE Arduino
- **Package**: ESP32 BLE Arduino
- **Version**: 2.0.0
- **License**: Apache-2.0
- **Source**: https://github.com/nkolban/ESP32_BLE_Arduino
- **Description**: Bluetooth Low Energy (BLE) library for ESP32

### Arduino MQTT Client
- **Package**: arduino-libraries/ArduinoMqttClient
- **Version**: 0.1.8
- **License**: MIT
- **Source**: https://github.com/arduino-libraries/ArduinoMqttClient
- **Description**: MQTT client library for Arduino

### ArduinoOTA
- **Package**: ArduinoOTA
- **License**: LGPL-2.1
- **Source**: https://github.com/esp8266/Arduino/tree/master/libraries/ArduinoOTA
- **Description**: Over-the-Air update functionality for ESP32

### ESPmDNS
- **Package**: ESPmDNS
- **License**: LGPL-2.1
- **Source**: https://github.com/espressif/arduino-esp32/tree/master/libraries/ESPmDNS
- **Description**: mDNS library for ESP32

### Wire
- **Package**: Wire
- **License**: LGPL-2.1
- **Source**: https://github.com/espressif/arduino-esp32/tree/master/libraries/Wire
- **Description**: I2C communication library for ESP32

### SD_MMC
- **Package**: SD_MMC
- **License**: LGPL-2.1
- **Source**: https://github.com/espressif/arduino-esp32/tree/master/libraries/SD_MMC
- **Description**: SD card interface using MMC protocol for ESP32

## Build Tools

### PlatformIO
- **License**: Apache-2.0
- **Source**: https://github.com/platformio/platformio-core
- **Description**: Cross-platform build system and library manager

### Boto3 (AWS SDK for Python)
- **License**: Apache-2.0
- **Source**: https://github.com/boto/boto3
- **Description**: Used in build scripts for S3 uploads and version management

## Note on License Compliance

This file is provided for informational purposes to acknowledge the third-party dependencies used in the BootBoots ESP32-CAM firmware project. Each dependency is subject to its own license terms. Users and contributors should review the license terms of each dependency before use or modification.

For full license texts, please refer to the respective project repositories or websites linked above.

Last Updated: August 3, 2025

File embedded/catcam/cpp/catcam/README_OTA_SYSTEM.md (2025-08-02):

# BootBoots S3-Based OTA Firmware Management System

## Overview

This system provides a complete Over-The-Air (OTA) firmware update solution for BootBoots ESP32 devices using S3 storage, web-based management, and Bluetooth communication.

## Architecture

```
Web App (React) ←→ Bluetooth ←→ ESP32 Device
     ↓                              ↓
  S3 Bucket ←→ Signed URLs ←→ HTTP Download
```

### Components

1. **ESP32 Firmware Components**
   - `version.h` - Version management
   - `OTAUpdate` - HTTP OTA downloads from S3
   - `BluetoothOTA` - Bluetooth command interface
   - `build_and_upload.py` - Automated build and S3 upload

2. **Web Application Components**
   - `FirmwareManager.tsx` - React UI for firmware management
   - `firmwareService.ts` - S3 integration and signed URLs
   - `bluetoothService.ts` - Web Bluetooth API communication

3. **S3 Storage Structure**
   ```
   mhsometestbucket/
   ├── BootBoots/
   │   ├── manifest.json
   │   ├── 1.0.0/
   │   │   └── firmware.bin
   │   ├── 1.1.0/
   │   │   └── firmware.bin
   │   └── ...
   └── MushroomHumidor/
       └── ...
   ```

## Setup Instructions

### 1. ESP32 Firmware Setup

1. **Install Dependencies**
   ```bash
   cd /path/to/bootboots/embedded/catcam/cpp/catcam
   pip install -r requirements.txt
   ```

2. **Configure Secrets**
   - Copy `include/secrets.h.template` to `include/secrets.h`
   - Set your WiFi credentials and OTA password

3. **Build and Upload Initial Firmware**
   ```bash
   # Build and upload to S3 (bumps version automatically)
   python scripts/build_and_upload.py
   
   # Build only (no S3 upload)
   python scripts/build_and_upload.py --build-only
   
   # Bump major/minor version
   python scripts/build_and_upload.py --version-type major
   ```

### 2. Web Application Setup

1. **Install Dependencies**
   ```bash
   cd /path/to/sandbox-app
   npm install
   ```

2. **Configure AWS Credentials**
   - Ensure your AWS credentials are configured for S3 access
   - Update S3 bucket name in `firmwareService.ts` if needed

3. **Start Development Server**
   ```bash
   npm start
   ```

### 3. S3 Bucket Setup

1. **Create S3 Bucket**
   ```bash
   aws s3 mb s3://mhsometestbucket
   ```

2. **Configure CORS** (for direct web access)
   ```json
   [
     {
       "AllowedHeaders": ["*"],
       "AllowedMethods": ["GET", "HEAD"],
       "AllowedOrigins": ["*"],
       "ExposeHeaders": []
     }
   ]
   ```

## Usage Workflow

### 1. Building and Deploying Firmware

```bash
# Automatic version bump and S3 upload
python scripts/build_and_upload.py

# Manual version specification
python scripts/build_and_upload.py --version-type minor
```

This will:
- Bump the version number in `version.h`
- Build the firmware using PlatformIO
- Upload `firmware.bin` to S3 at `BootBoots/{version}/firmware.bin`
- Update the `manifest.json` with the new version

### 2. Web-Based OTA Updates

1. **Open Web Application**
   - Navigate to the "Firmware Manager" tab
   - The system will automatically load available firmware versions from S3

2. **Connect to Device**
   - Click "Connect to BootBoots Device"
   - Select your ESP32 device from the Bluetooth dialog

3. **Deploy Firmware**
   - Select the desired firmware version
   - Click "Deploy Firmware Update"
   - Monitor progress in real-time

### 3. Update Process Flow

1. **Web App** → Generates signed S3 URL for selected firmware
2. **Web App** → Sends OTA command via Bluetooth to ESP32
3. **ESP32** → Receives signed URL and starts HTTP download
4. **ESP32** → Downloads firmware directly from S3
5. **ESP32** → Installs firmware and reboots
6. **ESP32** → Reports status back via Bluetooth

## API Reference

### Build Script Options

```bash
python scripts/build_and_upload.py [OPTIONS]

Options:
  --version-type {major,minor,patch}  Version bump type (default: patch)
  --no-bump                          Skip version bump
  --build-only                       Build without uploading to S3
```

### Bluetooth OTA Commands

The ESP32 accepts JSON commands via Bluetooth:

```json
{
  "action": "ota_update",
  "firmware_url": "https://signed-s3-url...",
  "version": "1.1.0"
}
```

```json
{
  "action": "get_status"
}
```

```json
{
  "action": "cancel_update"
}
```

### Status Responses

```json
{
  "status": "downloading",
  "message": "Downloading firmware: 45%",
  "progress": 45,
  "version": "1.0.0"
}
```

## Security Features

- **Password-Protected OTA**: ESP32 OTA updates require authentication
- **Signed URLs**: S3 firmware downloads use temporary signed URLs
- **Bluetooth Security**: BLE communication with characteristic-based access control
- **Version Verification**: Firmware versions are tracked and verified

## Troubleshooting

### Common Issues

1. **Build Script Fails**
   - Ensure PlatformIO is installed: `pip install platformio`
   - Check AWS credentials: `aws configure list`

2. **Bluetooth Connection Fails**
   - Ensure device is advertising (check serial logs)
   - Use Chrome/Edge browser (Web Bluetooth support required)
   - Check that ESP32 is within Bluetooth range

3. **S3 Upload Fails**
   - Verify AWS credentials and S3 permissions
   - Check bucket exists: `aws s3 ls s3://mhsometestbucket`

4. **Firmware Download Fails**
   - Check WiFi connectivity on ESP32
   - Verify signed URL is valid (check expiration)
   - Monitor ESP32 serial output for HTTP errors

### Debug Logs

**ESP32 Serial Output:**
```
[INFO] Bluetooth OTA service initialized successfully
[INFO] Received OTA command: {"action":"ota_update",...}
[INFO] Starting HTTP OTA update from: https://...
[INFO] Download progress: 50% (512000/1024000 bytes)
```

**Web Browser Console:**
```javascript
// Enable debug logging
localStorage.setItem('debug', 'firmware:*');
```

## File Structure

```
bootboots/embedded/catcam/cpp/catcam/
├── include/
│   ├── version.h              # Version management
│   └── secrets.h              # WiFi/OTA credentials
├── lib/
│   ├── OTAUpdate/             # HTTP OTA implementation
│   └── BluetoothOTA/          # Bluetooth OTA service
├── scripts/
│   └── build_and_upload.py    # Build automation
├── src/
│   └── main.cpp               # Main application
└── requirements.txt           # Python dependencies

sandbox-app/src/
├── components/pages/
│   ├── FirmwareManager.tsx    # React UI component
│   └── FirmwareManager.css    # Styling
└── services/
    ├── firmwareService.ts     # S3 integration
    └── bluetoothService.ts    # Bluetooth communication
```

## Version History

- **v1.0.0**: Initial S3-based OTA system
- **v1.1.0**: Added Bluetooth control interface
- **v1.2.0**: Enhanced progress monitoring and error handling

## Contributing

When adding new features:

1. Update version in `version.h`
2. Test with `--build-only` flag first
3. Update this README with new functionality
4. Deploy to S3 using the build script

## License

This OTA system is part of the BootBoots project. See main project LICENSE for details.

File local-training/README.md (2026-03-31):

# BootBoots — Local Training

Train and test the cat classifier on your M-series Mac, without going anywhere near SageMaker.

---

## How it all fits together

```
                    ┌─────────────────────────────────────────┐
                    │              AWS (existing)              │
                    │                                          │
                    │  DynamoDB: catadata                      │
                    │  ┌──────────────────────┐               │
                    │  │ imageName │ cat       │               │
                    │  │ 540.jpeg  │ Chi       │               │
                    │  │ 2025-07.. │ Boots     │               │
                    │  │ 2026-01.. │ Tau       │               │
                    │  └──────────────────────┘               │
                    │           │                              │
                    │           │ labels                       │
                    │           ▼                              │
                    │  S3: bootboots-images-…/catcam-training/ │
                    │  ┌────────────────────┐                  │
                    │  │ 540.jpeg           │                  │
                    │  │ 2025-07-29T21…jpg  │                  │
                    │  │ 2026-01-18T00…jpg  │                  │
                    │  └────────────────────┘                  │
                    └──────────────┬──────────────────────────┘
                                   │
                    download_data_multiclass.py
                    (reads labels + downloads images)
                                   │
                                   ▼
          ┌────────────────────────────────────────────────────┐
          │             local-training/data_multiclass/         │
          │                                                      │
          │  training/         (≈79% of images)                 │
          │  ├── Boots/                                          │
          │  ├── Chi/                                            │
          │  ├── Kappa/                                          │
          │  ├── Mu/                                             │
          │  ├── NoCat/                                          │
          │  ├── Tau/                                            │
          │  └── Wolf/                                           │
          │                                                      │
          │  validation/       (≈20% of images)                 │
          │  └── (same class dirs)                               │
          │        ← used during training each epoch             │
          │                                                      │
          │  manual_test/      (1% of images)                   │
          │  └── (same class dirs)                               │
          │        ← NEVER seen during training                  │
          └───────────────┬────────────────────────────────────┘
                          │
                    train_multiclass.py
                    (EfficientNetV2B1 on Metal GPU)
                          │
                          ▼
          ┌────────────────────────────┐
          │  local-training/models_multiclass/ │
          │                            │
          │  best_model.keras          │
          │  class_names.json          │
          └──────────────┬─────────────┘
                         │
               predict.py / serve.py
               (manual testing + sandbox badge)
```

---

## The two filename formats

The catcam has used two naming schemes over time:

| Era | Format | Example |
|-----|---|---|
| Pre-2026 (old) | Numeric | `540.jpeg` |
| 2025 onwards | ISO timestamp | `2025-07-29T21-20-54-225Z.jpg` |

`download_data_multiclass.py` handles both transparently. The old images also had
a bug where they were saved without a JPEG end-of-file marker — the script patches
those automatically as it downloads them.

---

## Model architecture

The classifier is built on **EfficientNetV2B1** (ImageNet pretrained), with a
GlobalAveragePooling → Dropout → Dense(7, softmax) head. Input resolution: 240×240.

At inference time the seven-class output collapses to a binary spray decision:
`Boots → spray`, anything else → don't spray.

Data augmentation runs in the **data pipeline** (not inside the model), applied to
training images only:

| Augmentation | Value | Rationale |
|---|---|---|
| `RandomFlip` | horizontal only | Cats on a floor; vertical flips aren't realistic |
| `RandomRotation` | ±15% | Fixed camera — extreme rotation unlikely |
| `RandomZoom` | zoom in 0–30% | Handles cats not filling the frame |
| `RandomContrast` | ±20% | Kitchen lighting varies by time of day |
| `RandomBrightness` | ±20% | Same reason |

Keeping augmentation out of the model means `export_for_sagemaker.py` can use a
simple `tf.saved_model.save()` call — no serialisation workarounds needed.

---

## Setup (first time only)

You need Python 3.11 (TensorFlow doesn't support 3.12+ yet).

```bash
# Select Python 3.11 via asdf
asdf shell python 3.11.x

cd local-training

# Create a virtual environment
python -m venv .venv
source .venv/bin/activate

# Install dependencies (tensorflow-metal gives you M-series GPU acceleration)
pip install -r requirements.txt
```

---

## Workflow

### Step 1 — Download the data

```bash
AWS_PROFILE=nakom.is-sandbox python download_data_multiclass.py
```

This creates the `data_multiclass/` directory structure shown in the diagram above.
It's safe to re-run — already-downloaded images are skipped.

Optional flags:
```
--dest data_multiclass   Where to put the data (default: data_multiclass)
--max-nocat 600          Cap NoCat to limit class imbalance (default: 600)
--manual-pct 1.0         Percentage held back for manual testing (default: 1.0)
--val-split 0.2          Fraction of remaining used for validation (default: 0.2)
```

### Step 2 — Find a good learning rate (optional but recommended)

Before committing to a full training run, find a good learning rate:

```bash
python train_multiclass.py --find-lr
```

This runs a learning rate range test (1e-6 → 1e-1 over 100 steps), prints the
suggested rate, and saves `lr_finder.png`. Look for the point of steepest descent
before the loss diverges. Use that value (or 3–10× lower) as `--lr`.

### Step 3 — Train

```bash
python train_multiclass.py
```

Or with a learning rate from the finder:
```bash
python train_multiclass.py --lr 3e-4
```

You'll see output like this each epoch:
```
Epoch 12/50
 - loss: 0.3241 - accuracy: 0.8812 - val_loss: 0.2918 - val_accuracy: 0.9043
```

`val_accuracy` is the one to watch. Training stops automatically once it stops
improving (`--patience 10` means 10 epochs with no improvement).

The best model is saved to `models_multiclass/` automatically.

Optional flags:
```
--lr 0.0001          Learning rate (default: 0.0001; use --find-lr first)
--epochs 50          Max epochs before giving up (default: 50)
--batch-size 16      Images processed at once
--patience 10        Early stopping patience in epochs (default: 10)
--train-base         Also fine-tune the EfficientNetV2B1 base (slower, often better)
--dropout 0.3        Dropout rate (default: 0.3)
--l2 0.0001          L2 regularisation weight (default: 0.0001)
```

**Recommended starting point:** `--find-lr` first, then `--lr <suggested> --train-base`

`--train-base` unfreezes the EfficientNetV2B1 backbone so it adapts to cat-specific
visual patterns rather than relying purely on ImageNet features. It runs slower per
epoch but reaches meaningfully higher accuracy — especially for visually similar
classes (Boots/Kappa/Chi). Early stopping typically kicks in around epoch 20–25.

### Step 4 — Troubleshooting

| Problem | Things to try |
|---|---|
| Low accuracy overall | Add `--train-base`; run `--find-lr` and set a better `--lr` |
| Overfitting (train acc >> val acc) | Higher `--dropout 0.5`; higher `--l2 0.001` |
| One class dominates | Adjust per-class caps in the download script |

### Step 5 — Test with the manual test set

```bash
python predict.py data_multiclass/manual_test/Boots/
python predict.py data_multiclass/manual_test/Chi/
```

Or test a specific image:
```bash
python predict.py data_multiclass/manual_test/Boots/2025-07-29T21-20-54-225Z.jpg
```

---

## Deploying to production

Once you're happy with the model:

```bash
./deploy_model.sh
```

This script:
1. Exports `models_multiclass/best_model.keras` to TF Serving SavedModel format
2. Packages it as `model.tar.gz`
3. Uploads to S3
4. Creates a new SageMaker model + endpoint config (timestamped names)
5. Updates the live `bootboots` endpoint in-place
6. Waits for `InService`

Remember to also update `CAT_NAMES` in `infra/lambda/infer-lambda/src/handler.ts`
and redeploy the Lambda if the class list has changed.

---

## Sandbox app integration

The sandbox labelling UI shows a prediction badge for each image using a local
inference server. The badge appears only when the server is running — entirely opt-in.

```
Browser (sandbox.nakomis.com)            Your Mac
┌──────────────────────────────┐         ┌────────────────────────────────┐
│  BootBootsPage.tsx           │         │  serve.py  (localhost:8765)    │
│                              │         │                                │
│  [cat image]                 │  POST   │  POST /predict                 │
│  ┌──────────────────────┐    │────────►│  raw JPEG bytes                │
│  │ Boots  92%           │    │◄────────│  { prediction, confidence }    │
│  └──────────────────────┘    │         │                                │
│  (green = Boots, grey = not) │         │  loads models_multiclass/      │
└──────────────────────────────┘         │         best_model.keras       │
                                         └────────────────────────────────┘
```

Start the server:
```bash
./serve.sh
```

Or manually:
```bash
source .venv/bin/activate
python serve.py
```

---

## Files

| File | What it does |
|---|---|
| `download_data_multiclass.py` | Downloads images from S3/DynamoDB, one class per cat |
| `download_data.py` | Legacy binary (Boots/NotBoots) download script |
| `train_multiclass.py` | Trains the EfficientNetV2B1 seven-class classifier |
| `train_local.py` | Legacy binary (Boots/NotBoots) training script |
| `predict.py` | Runs the trained model on one or more images |
| `serve.py` | Inference server for the sandbox app badge (localhost:8765) |
| `serve.sh` | Convenience script to start `serve.py` in the venv |
| `export_for_sagemaker.py` | Exports `.keras` model to TF Serving SavedModel + `model.tar.gz` |
| `deploy_model.sh` | Full deploy pipeline: export → S3 upload → SageMaker endpoint update |
| `requirements.txt` | Python dependencies |
| `data/` | Created by `download_data.py` — not committed to git |
| `data_multiclass/` | Created by `download_data_multiclass.py` — not committed to git |
| `models/` | Created by `train_local.py` — not committed to git |
| `models_multiclass/` | Created by `train_multiclass.py` — not committed to git |

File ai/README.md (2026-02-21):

# BootBoots AI Training Guide

This guide covers training a cat recognition model using SageMaker and deploying it as a serverless inference endpoint.

## Overview

The system trains a transfer learning model (MobileNet v2 base) as a **binary classifier**:
- **Boots** — neighbour's cat to deter (trigger water spray)
- **NotBoots** — everyone else: household cats (Chi, Kappa, Mu, Tau, Wolf) and no-cat frames

> **Previous multi-class model** (7 classes) is preserved at git tag `multi-cat-recognition`.

### Architecture

```
┌─────────────────┐     ┌──────────────────┐     ┌─────────────────┐
│  catcam-training│     │   Data Prep      │     │ training-data   │
│  (raw images)   │────▶│   Lambda         │────▶│ (by class)      │
│  + catadata DB  │     │                  │     │                 │
└─────────────────┘     └──────────────────┘     └────────┬────────┘
                                                          │
                        ┌──────────────────┐              │
                        │  SageMaker       │◀─────────────┘
                        │  Training Job    │
                        └────────┬─────────┘
                                 │
                        ┌────────▼─────────┐
                        │  Model Artifacts │
                        │  (S3)            │
                        └────────┬─────────┘
                                 │
                        ┌────────▼─────────┐
                        │  Serverless      │
                        │  Endpoint        │
                        └──────────────────┘
```

## Project Structure

```
infra/
├── bin/
│   └── infra.ts                 # CDK app (includes AiTrainingStack)
├── lib/
│   ├── ai-training-stack.ts     # Training & inference infrastructure
│   └── ...
├── lambda/
│   ├── ai-data-prep/            # Prepares training data from catadata table
│   │   └── src/handler.ts
│   └── ai-training-trigger/     # Triggers SageMaker training job
│       └── src/handler.ts
├── training/
│   └── train.py                 # Custom MobileNet v2 training script
└── ...

ai/
├── README.md                    # This guide
└── scripts/                     # Utility scripts (optional)
```

### Training Script

`infra/training/train.py` is a self-contained Python/Keras script that runs inside the SageMaker TensorFlow container. It:
- Loads images from the `training/` and `validation/` S3 input channels
- Fine-tunes MobileNet v2 (ImageNet weights) with a custom classification head
- Applies data augmentation, dropout, L2 regularisation, and early stopping
- Saves a versioned SavedModel to `/opt/ml/model/1/` (TF Serving format)
- Writes `class_names.json` alongside the model for inference mapping

**CDK packages `infra/training/` as a zip asset and uploads it to S3 automatically on every `cdk deploy`.** The trigger Lambda passes the S3 URI to SageMaker as `sagemaker_submit_directory`. No manual script management needed.

## Quick Start

### 1. Deploy the Training Stack

```bash
cd infra
AWS_PROFILE=nakom.is-sandbox npx cdk deploy BootBootsAiTrainingStack
```

This creates:
- `bootboots-training-data-{account}` - S3 bucket for organized training data
- `bootboots-models-{account}` - S3 bucket for model artifacts
- `bootboots-data-prep` - Lambda for preparing training data
- `bootboots-trigger-training` - Lambda for starting training jobs
- IAM role for SageMaker

### 2. Trigger Training

Use `--invocation-type Event` (async) - the data prep step takes ~90 seconds which can cause the CLI to time out if invoked synchronously, even though the Lambda itself completes fine.

```bash
AWS_PROFILE=nakom.is-sandbox aws lambda invoke \
  --function-name bootboots-trigger-training \
  --region eu-west-2 \
  --invocation-type Event \
  --payload '{}' \
  --cli-binary-format raw-in-base64-out \
  response.json
```

A `StatusCode: 202` response means the job was accepted. Monitor via SageMaker console or the commands below.

This will:
1. Read labeled images from `catadata` DynamoDB table
2. Copy images to organized folder structure (training/validation split)
3. Undersample the NoCat class to prevent bias
4. Start a SageMaker training job

### 3. Monitor Training

```bash
# Check training job status
AWS_PROFILE=nakom.is-sandbox aws sagemaker describe-training-job \
  --training-job-name <job-name-from-response> \
  --region eu-west-2 \
  --query '{Status:TrainingJobStatus,Metrics:FinalMetricDataList}'

# Watch CloudWatch logs
AWS_PROFILE=nakom.is-sandbox aws logs tail \
  /aws/sagemaker/TrainingJobs \
  --follow \
  --region eu-west-2
```

### 4. Deploy Trained Model (After Training Completes)

```bash
# Get the model artifact path from completed training job
AWS_PROFILE=nakom.is-sandbox aws sagemaker describe-training-job \
  --training-job-name <job-name> \
  --region eu-west-2 \
  --query 'ModelArtifacts.S3ModelArtifacts' \
  --output text

# Deploy with the model
AWS_PROFILE=nakom.is-sandbox npx cdk deploy BootBootsAiTrainingStack \
  --context modelDataUrl=s3://bootboots-models-975050268859/training-output/<job-name>/output/model.tar.gz
```

## Training Configuration

### Hyperparameters

Defaults are baked into the trigger Lambda; override by passing a payload (see Custom Training Parameters below).

| Lambda parameter | Default | Description |
|---|---|---|
| `epochs` | 50 | Max training epochs (early stopping usually triggers sooner) |
| `learningRate` | 0.0001 | Adam optimiser learning rate |
| `batchSize` | 16 | Images per batch |
| `trainOnlyTopLayer` | false | `false` = fine-tune whole network, `true` = classifier head only |

Fixed in `train.py` (edit the script to change):

| Setting | Value | Description |
|---|---|---|
| Dropout | 0.3 | Applied before final Dense layer |
| L2 regularisation | 0.0001 | Applied to Dense layer weights |
| Augmentation | on | Random flip, rotation ±30%, zoom ±20% |
| Early stopping patience | 10 epochs | Monitors `val_accuracy`, restores best weights |
| Early stopping min delta | 0.001 | Minimum improvement to reset patience counter |
| Image size | 224×224 | MobileNet v2 native input size |

## Addressing Class Imbalance

Binary class distribution (as of Feb 2026):
- **Boots**: ~190 images
- **NotBoots**: ~2874 images (Chi 196, Tau 255, Kappa 235, Mu 62, Wolf 59, NoCat 2067) → capped at 600

The data prep Lambda caps NotBoots at `MAX_NOTBOOTS_SAMPLES` (default 600, ~3× Boots) by randomly sampling from the full NotBoots pool, ensuring variety across all cat types and NoCat frames.

**Source images:**
- New images (catcam): `bootboots-images-{account}-{region}/catcam-training/` (timestamp-named `.jpg` files)
- Old images (pre-2026): numeric-named `.jpeg` files in the same prefix (migrated from `bootbootstraining` bucket in Feb 2026; were truncated JPEGs, patched with FF D9 EOI marker by the data prep Lambda on copy)

**Implemented strategies:**
1. **Undersampling NotBoots** — capped at `MAX_NOTBOOTS_SAMPLES` (default 600)
2. **Data augmentation** — synthetic variations
3. **Stratified split** — proportional validation set

**To improve Boots detection:**
- Collect more Boots images from the catcam (he visits regularly)
- More diverse angles/lighting in Boots training data

## Serverless Inference

The endpoint is configured for pay-per-request:

| Setting | Value |
|---|---|
| Memory | 2048 MB |
| Max concurrency | 5 |
| Cold start | 2-5 seconds |
| Cost per request | ~$0.00012 |

## Custom Training Parameters

Pass a JSON payload to override defaults (use `--invocation-type Event` for async):

```bash
AWS_PROFILE=nakom.is-sandbox aws lambda invoke \
  --function-name bootboots-trigger-training \
  --region eu-west-2 \
  --invocation-type Event \
  --payload '{"epochs": 100, "learningRate": 0.00005, "batchSize": 32}' \
  --cli-binary-format raw-in-base64-out \
  response.json
```

| Option | Type | Description |
|---|---|---|
| `skipDataPrep` | bool | Skip S3 data reorganisation (reuse existing training/validation split) |
| `epochs` | int | Max training epochs |
| `learningRate` | float | Adam learning rate |
| `batchSize` | int | Images per batch |
| `trainOnlyTopLayer` | bool | Only train the classifier head (faster, less accurate) |

## Troubleshooting

### Training job fails immediately
- Check IAM role has S3 and ECR permissions
- Verify training data exists: `aws s3 ls s3://bootboots-training-data-975050268859/training/`
- If error is `AccessDeniedException: sagemaker:AddTags` - the trigger Lambda's IAM policy is missing `sagemaker:AddTags`. Add it to the policy in `infra/lib/ai-training-stack.ts` and redeploy.

### CDK deploy fails with Docker error
- CDK requires Docker running to bundle Lambda assets. Open Docker Desktop and retry.

### Poor accuracy
- Check class distribution in data prep output
- Try more epochs or lower learning rate
- Collect more data for underrepresented classes

### Data prep timeout
- Lambda has 10 minute timeout
- For very large datasets, consider Step Functions

### Endpoint cold start too slow
- Increase memory (max 6144 MB)
- Consider provisioned concurrency for latency-critical apps

## Cost Estimates

| Resource | Cost | Notes |
|---|---|---|
| Training (ml.m5.xlarge) | ~$0.23/hr | ~30-60 min typical |
| Serverless inference | ~$0.00012/req | Plus memory cost |
| S3 storage | ~$0.023/GB/mo | Training data + models |

**Estimated monthly:**
- Low usage (100 inferences/day): < $5
- Medium (1000/day): ~$15
- Training runs: ~$0.50 each

## Local Inference

Run the latest trained model against local JPEG images without deploying anything.

### Setup (one-time)

```bash
# Use Python 3.11 (TensorFlow doesn't support 3.13)
ASDF_PYTHON_VERSION=3.11.14 pip install tensorflow boto3

# Or if you have a virtualenv:
ASDF_PYTHON_VERSION=3.11.14 python -m venv ~/.venvs/bootboots
source ~/.venvs/bootboots/bin/activate
pip install tensorflow boto3
```

### Run

```bash
cd infra  # repo root / wherever you have AWS credentials
export AWS_PROFILE=nakom.is-sandbox

# Classify one or more images (downloads + caches model automatically)
ASDF_PYTHON_VERSION=3.11.14 python ai/scripts/infer_local.py path/to/image.jpg

# Multiple images at once
ASDF_PYTHON_VERSION=3.11.14 python ai/scripts/infer_local.py ignored/testimages/**/*.jpg

# Force re-download the model (e.g. after a new training run)
ASDF_PYTHON_VERSION=3.11.14 python ai/scripts/infer_local.py --refresh image.jpg

# Use a specific training job instead of the latest
ASDF_PYTHON_VERSION=3.11.14 python ai/scripts/infer_local.py --job bootboots-2026-02-21T16-29-42 image.jpg
```

### Example output

```
chi.jpg
  Boots=2.3%  NotBoots=97.7%
  => NotBoots (97.7%)

boots_catcam.jpg
  Boots=96.1%  NotBoots=3.9%
  => Boots (96.1%)
```

The model is cached at `~/.cache/bootboots/model/<job-name>/` after the first download.

## Next Steps

1. ~~Deploy the training stack~~ ✓ Done
2. ~~Write custom training script~~ ✓ Done (`infra/training/train.py`, Feb 2026)
3. ~~Switch to binary Boots/NotBoots classifier~~ ✓ Done (Feb 2026, 94.9% val accuracy)
4. ~~Deploy model to serverless endpoint~~ ✓ Done (endpoint: `bootboots`)
5. Integrate inference endpoint into the catcam spray trigger pipeline
6. Collect more Boots catcam images to further improve recall

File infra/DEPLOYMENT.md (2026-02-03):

# Firmware Cleanup Lambda - Deployment Guide

## Prerequisites

1. AWS CLI configured with appropriate credentials
2. AWS CDK CLI installed (`npm install -g aws-cdk`)
3. Node.js 22.x or later
4. Access to the `nakomis-firmware-updates` S3 bucket

## Deployment Steps

### 1. Install Dependencies

```bash
cd /Users/martinmu_1/repos/nakomis/bootboots/infra
npm install
```

### 2. Bootstrap CDK (if not already done)

```bash
cdk bootstrap aws://<ACCOUNT_ID>/<REGION>
```

Replace `<ACCOUNT_ID>` and `<REGION>` with your AWS account ID and region.

### 3. Review the Stack

```bash
cdk synth BootBootsFirmwareCleanupStack
```

This will show you the CloudFormation template that will be created.

### 4. Deploy the Stack

```bash
export AWS_PROFILE=nakom.is-sandbox  # or your AWS profile
cdk deploy BootBootsFirmwareCleanupStack
```

**Note:** The deployment will create:
- Lambda function: `FirmwareCleanupLambda`
- CloudWatch Log Group: `/aws/lambda/FirmwareCleanupLambda`
- IAM role with S3 permissions
- S3 event notification (via `addEventNotification`)

### 5. Verify Deployment

After deployment, you'll see output like this:

```
BootBootsFirmwareCleanupStack.CleanupLambdaArn = arn:aws:lambda:eu-west-2:...
BootBootsFirmwareCleanupStack.CleanupLambdaName = FirmwareCleanupLambda
BootBootsFirmwareCleanupStack.LogGroupName = /aws/lambda/FirmwareCleanupLambda
BootBootsFirmwareCleanupStack.NotificationStatus = S3 event notification configured via addEventNotification
BootBootsFirmwareCleanupStack.S3BucketName = nakomis-firmware-updates
```

**Note:** The S3 event notification is configured automatically by CDK using `bucket.addEventNotification()`. No manual setup required!

Check that the Lambda was created:

```bash
aws lambda get-function --function-name FirmwareCleanupLambda
```

Check CloudWatch Logs:

```bash
aws logs describe-log-groups --log-group-name-prefix /aws/lambda/FirmwareCleanupLambda
```

## Testing the Deployment

### Test 1: Upload a Firmware File

```bash
cd /Users/martinmu_1/repos/nakomis/bootboots/embedded/catcam/cpp/catcam
python scripts/build_and_upload.py --version-type patch
```

Expected output:
```
✅ Successfully uploaded firmware v1.0.55 to S3
📝 Note: Manifest will be updated automatically by Lambda
🎉 Ready for OTA deployment via web interface!
```

### Test 2: Check Lambda Execution

View CloudWatch Logs:

```bash
aws logs tail /aws/lambda/FirmwareCleanupLambda --follow
```

Or in AWS Console:
1. CloudWatch → Log groups → `/aws/lambda/FirmwareCleanupLambda`
2. Click on the latest log stream
3. Verify you see logs like:
   ```
   Firmware Cleanup Lambda triggered
   Processing: s3://nakomis-firmware-updates/BootBoots/1.0.55/firmware.bin
   Found 4 total firmware versions
   Keeping 3 versions, deleting 1 versions
   ✅ Deleted: BootBoots/1.0.51/firmware.bin
   ✅ Updated manifest: BootBoots/manifest.json
   ✅ All records processed
   ```

### Test 3: Verify Manifest

Check the manifest was updated:

```bash
aws s3 cp s3://nakomis-firmware-updates/BootBoots/manifest.json - | python -m json.tool
```

Expected output:
```json
{
  "project": "BootBoots",
  "versions": [
    {
      "version": "1.0.55",
      "timestamp": "2025-10-11T12:00:00.000Z",
      "firmware_path": "BootBoots/1.0.55/firmware.bin",
      "size": 1940992
    },
    {
      "version": "1.0.54",
      ...
    },
    {
      "version": "1.0.53",
      ...
    }
  ]
}
```

### Test 4: Verify Old Versions Deleted

List S3 files:

```bash
aws s3 ls s3://nakomis-firmware-updates/BootBoots/ --recursive
```

You should see only 3 firmware versions (plus manifest.json).

## Updating the Lambda

After making code changes:

```bash
cd /Users/martinmu_1/repos/nakomis/bootboots/infra
cdk deploy BootBootsFirmwareCleanupStack
```

CDK will automatically rebuild and deploy the updated Lambda code.

## Rollback

To remove the Lambda:

```bash
cdk destroy BootBootsFirmwareCleanupStack
```

**Warning:** This will delete:
- Lambda function
- CloudWatch Logs
- S3 bucket notification configuration (automatically removed)

The S3 bucket and its contents are NOT affected.

## Troubleshooting

### Error: "Unable to validate the following destination configurations"

**Cause:** S3 doesn't have permission to invoke the Lambda.

**Fix:** The Lambda's resource-based policy is automatically created by the CDK stack via `cleanupLambda.addPermission()`. If you see this error, redeploy the stack:

```bash
cdk deploy BootBootsFirmwareCleanupStack --force
```

### Error: "AccessDenied" when deleting S3 objects

**Cause:** Lambda IAM role doesn't have `s3:DeleteObject` permission.

**Fix:** Check the CDK stack - permissions should be automatically granted. If not:

```bash
# Check the Lambda's role
aws lambda get-function --function-name FirmwareCleanupLambda --query 'Configuration.Role'

# Verify the role has S3 permissions
aws iam list-attached-role-policies --role-name <ROLE_NAME>
```

### Lambda not triggering

1. **Check S3 event notification exists:**
   ```bash
   aws s3api get-bucket-notification-configuration --bucket nakomis-firmware-updates
   ```

2. **Check Lambda permissions:**
   ```bash
   aws lambda get-policy --function-name FirmwareCleanupLambda
   ```

3. **Test manually:**
   ```bash
   aws lambda invoke \
     --function-name FirmwareCleanupLambda \
     --payload file://test-event.json \
     response.json
   ```

## Monitoring

### CloudWatch Metrics

Monitor Lambda execution:

```bash
aws cloudwatch get-metric-statistics \
  --namespace AWS/Lambda \
  --metric-name Invocations \
  --dimensions Name=FunctionName,Value=FirmwareCleanupLambda \
  --start-time 2025-10-11T00:00:00Z \
  --end-time 2025-10-11T23:59:59Z \
  --period 3600 \
  --statistics Sum
```

### Set up CloudWatch Alarms (Optional)

Create an alarm for Lambda errors:

```bash
aws cloudwatch put-metric-alarm \
  --alarm-name FirmwareCleanupLambdaErrors \
  --alarm-description "Alert on FirmwareCleanupLambda errors" \
  --metric-name Errors \
  --namespace AWS/Lambda \
  --statistic Sum \
  --period 300 \
  --threshold 1 \
  --comparison-operator GreaterThanThreshold \
  --evaluation-periods 1 \
  --dimensions Name=FunctionName,Value=FirmwareCleanupLambda
```

## Cost Estimation

**Lambda:**
- Execution time: ~2-5 seconds per invocation
- Memory: 256 MB
- Invocations: ~10-50 per month (depends on firmware release frequency)
- **Estimated cost:** < $0.01/month (well within free tier)

**CloudWatch Logs:**
- Log data: ~1 KB per invocation
- Retention: 6 months
- **Estimated cost:** < $0.01/month

**S3:**
- Storage reduction: ~1.9 MB per deleted version
- If releasing daily, saves ~57 MB/month
- **Cost savings:** ~$0.001/month in S3 storage

## Security Considerations

1. **Least Privilege:** Lambda has minimal S3 permissions
2. **No Public Access:** Lambda is not exposed to the internet
3. **CloudWatch Logs:** No sensitive data logged
4. **S3 Event Filter:** Only triggers on `firmware.bin` files

## Next Steps

After deployment:

1. Upload a few firmware versions to test the cleanup
2. Monitor CloudWatch Logs for any issues
3. Set up CloudWatch Alarms for production monitoring
4. Update documentation if you add more projects

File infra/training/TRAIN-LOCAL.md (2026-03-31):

# Running Training Locally

## Prerequisites

Python 3.11 is required (TensorFlow 2.12 does not support 3.13+):

```bash
asdf shell python 3.11.x
pip install tensorflow==2.12.* pillow
```

## Data layout

Training data must be organised into class subfolders:

```
data/
  training/
    Boots/
      img1.jpg
      img2.jpg
    NotBoots/
      img1.jpg
  validation/
    Boots/
      ...
    NotBoots/
      ...
```

Source images are in S3 under `catcam-training/` (Boots) and `catcam-images/` (NotBoots) in the images bucket (`bootboots-images-<account>-eu-west-2`). Download them with:

```bash
BUCKET=$(AWS_PROFILE=nakom.is-sandbox aws s3api list-buckets \
  --query "Buckets[?starts_with(Name, 'bootboots-images')].Name | [0]" \
  --output text)

AWS_PROFILE=nakom.is-sandbox aws s3 sync s3://$BUCKET/catcam-training/ data/training/Boots/
AWS_PROFILE=nakom.is-sandbox aws s3 sync s3://$BUCKET/catcam-images/   data/training/NotBoots/
```

Split roughly 80/20 into `data/validation/` manually.

> **Note:** NotBoots images are capped at 600 during SageMaker data prep to limit class imbalance — consider doing the same locally.

## Running

```bash
cd infra/training

SM_CHANNEL_TRAINING=data/training \
SM_CHANNEL_VALIDATION=data/validation \
SM_MODEL_DIR=output/model \
SM_OUTPUT_DATA_DIR=output/data \
python train.py
```

## Hyperparameters

Key hyperparameters can be overridden via a JSON file at `/opt/ml/input/config/hyperparameters.json`, or by editing the defaults at the top of `train.py`:

| Parameter | Default | Notes |
|---|---|---|
| `epochs` | 50 | Reduced by early stopping |
| `learning_rate` | 0.0001  | Adam optimiser |
| `batch_size` | 16 | |
| `num_classes` | **7** | **Override to `2` for Boots/NotBoots** |
| `dropout_rate` | 0.3 | |
| `regularizers_l2` | 0.0001  | L2 kernel regularisation |
| `train_only_top_layer` | False | False = fine-tune full network |
| `augmentation` | True | Random flip/rotation/zoom |
| `early_stopping` | True | |
| `early_stopping_patience`  | 10 | Epochs to wait before stopping |
| `early_stopping_min_delta` | 0.001 | Minimum val_accuracy improvement |

> The `num_classes` default in `train.py` is `7` (legacy multi-class model). For the current binary classifier always pass `num_classes=2`.

## Output

The SavedModel is written to `output/model/1/` with a `serving_default` signature that accepts base64-encoded JPEG bytes — no pre-resizing needed. A `class_names.json` is also written alongside the model.

## Deploying the retrained model

Once satisfied with local results, trigger a full SageMaker training run to produce a deployable artifact:

```bash
AWS_PROFILE=nakom.is-sandbox aws lambda invoke \
  --function-name bootboots-trigger-training \
  --region eu-west-2 \
  --invocation-type Event \
  --payload '{}' \
  --cli-binary-format raw-in-base64-out \
  /tmp/response.json
```

> Use `--invocation-type Event` (async) — data prep takes ~90s and will time out if invoked synchronously.

Monitor the job in the [SageMaker console](https://eu-west-2.console.aws.amazon.com/sagemaker/home?region=eu-west-2#/training-jobs) or via:

```bash
AWS_PROFILE=nakom.is-sandbox aws sagemaker describe-training-job \
  --training-job-name <job-name> \
  --region eu-west-2 \
  --query 'TrainingJobStatus'
```

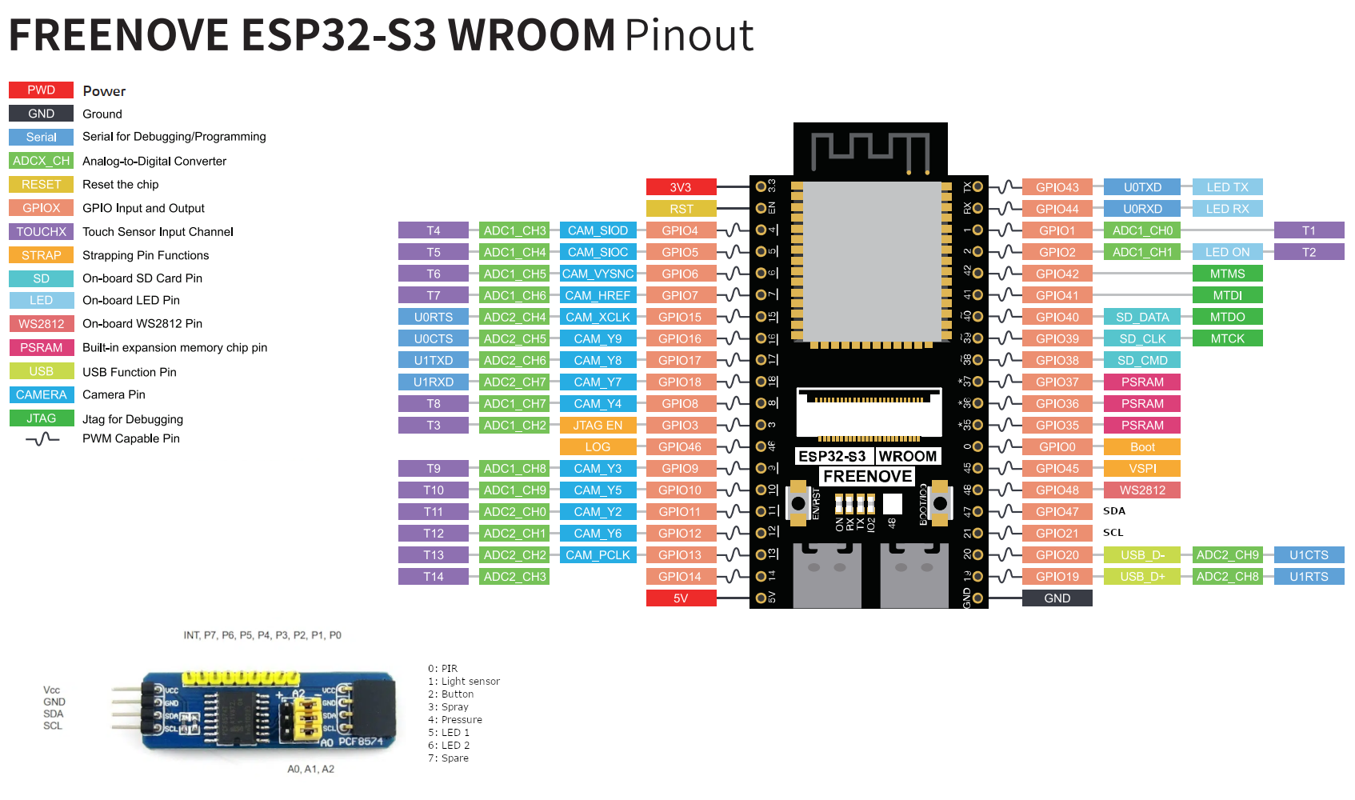
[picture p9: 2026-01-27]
docs/bootboots-pinout.png

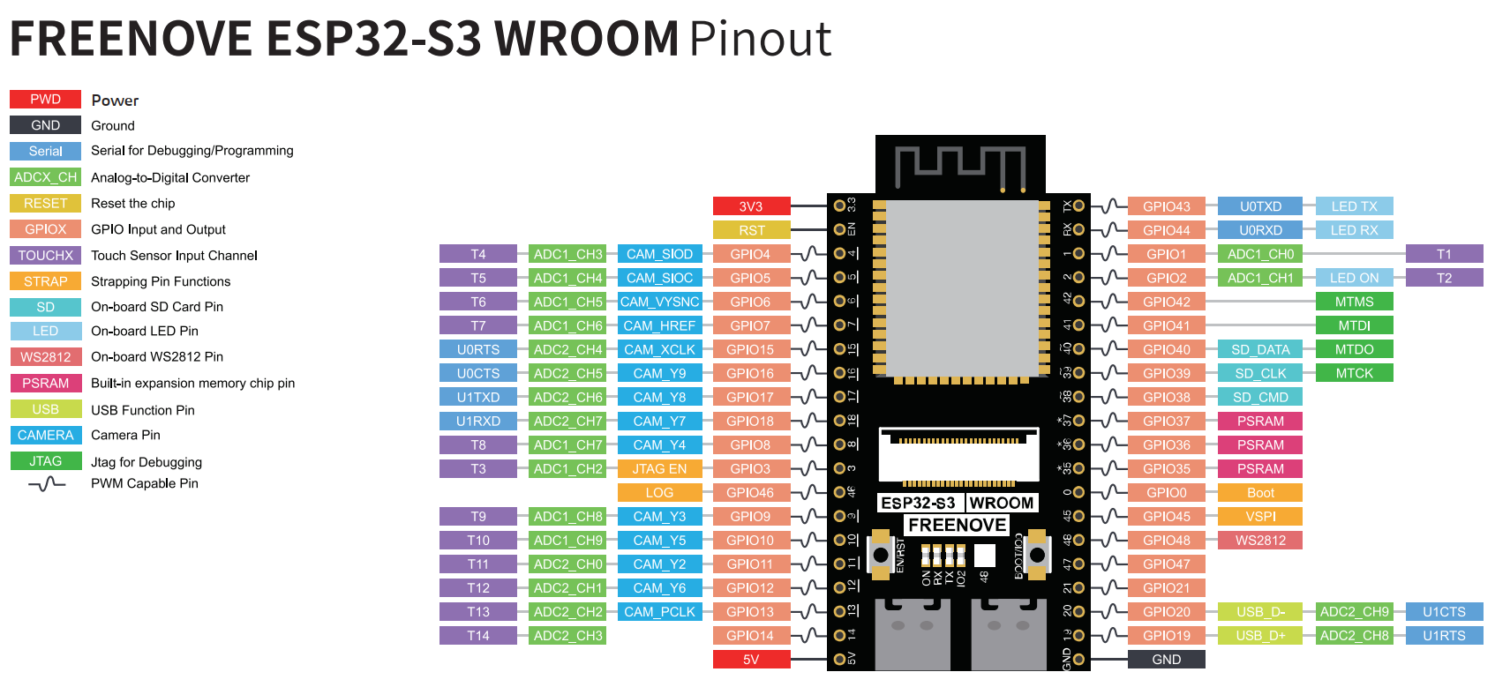
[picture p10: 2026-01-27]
docs/ESP32S3-CAM.png

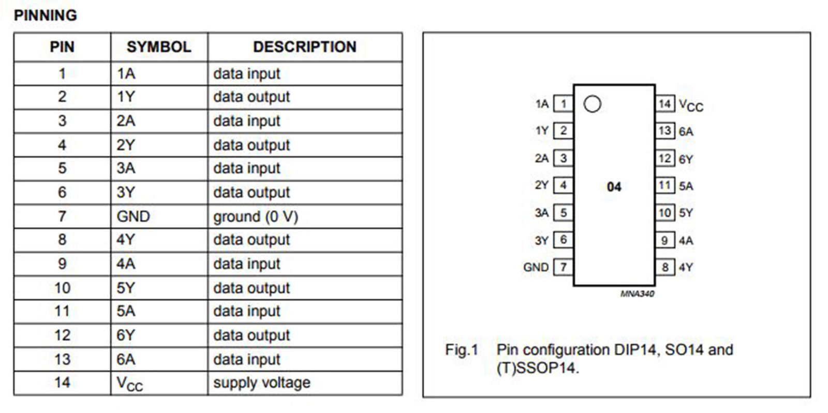
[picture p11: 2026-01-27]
docs/SN74HC04N-Hex-Inverter.jpeg

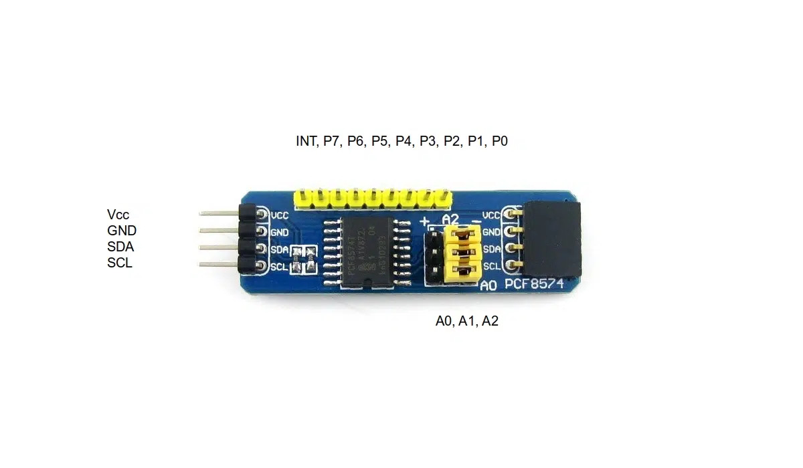
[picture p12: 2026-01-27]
docs/PFC8574.jpg

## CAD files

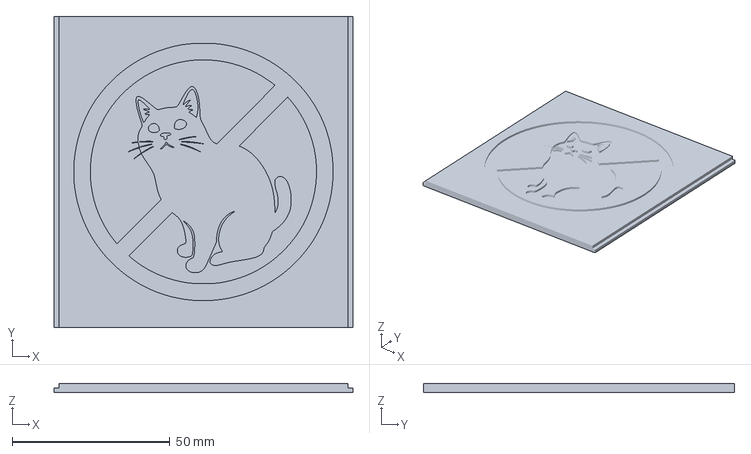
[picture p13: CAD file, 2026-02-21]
3d/BBLid.3mf
94.6 x 98.5 x 3.00 mm

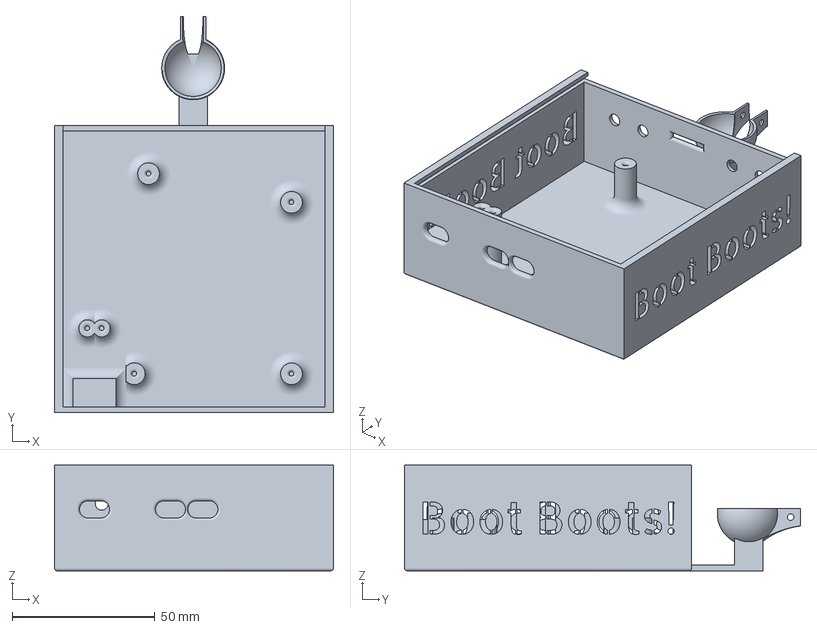
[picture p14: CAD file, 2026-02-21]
3d/BBBase.3mf
97.6 x 138.7 x 37.0 mm

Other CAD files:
3d/bootboots.stl
3d/BBBase.stl
3d/BBLid.stl

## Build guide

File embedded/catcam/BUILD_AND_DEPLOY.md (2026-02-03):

# BootBoots Firmware Build & Deployment Guide

## Quick Start

```bash
# Install Python dependencies
pip install -r requirements.txt

# Build firmware and upload to S3
python scripts/build_and_upload.py

# Build only (no upload)
python scripts/build_and_upload.py --build-only
```

---

## Prerequisites

### 1. Development Tools
- **PlatformIO** - `pip install platformio`
- **Python 3.7+** with boto3 - `pip install -r requirements.txt`
- **AWS CLI** configured with credentials

### 2. AWS Setup
- S3 bucket: `nakomis-firmware-updates`
- IAM permissions: `s3:PutObject`, `s3:GetObject`, `s3:ListBucket`

### 3. ESP32 Configuration
- Copy `include/secrets.h.template` to `include/secrets.h`
- Set WiFi credentials and OTA password

---

## Build Script Usage

### Basic Commands

```bash
# Patch version bump (1.0.0 → 1.0.1)
python scripts/build_and_upload.py

# Minor version bump (1.0.1 → 1.1.0)
python scripts/build_and_upload.py --version-type minor

# Major version bump (1.1.0 → 2.0.0)
python scripts/build_and_upload.py --version-type major

# Build without version bump
python scripts/build_and_upload.py --no-bump

# Build only (no S3 upload)
python scripts/build_and_upload.py --build-only
```

### What the Script Does

1. **Version Management**
   - Reads current version from `include/version.h`
   - Bumps version according to semantic versioning
   - Updates `version.h` with new version

2. **Build Process**
   - Cleans previous build artifacts
   - Compiles firmware using PlatformIO
   - Generates `firmware.bin` in `.pio/build/esp32cam/`

3. **S3 Upload**
   - Uploads firmware to `s3://nakomis-firmware-updates/BootBoots/{version}/firmware.bin`
   - Updates `manifest.json` with version metadata
   - Adds file size and timestamp information

---

## S3 Bucket Structure

```
nakomis-firmware-updates/
├── BootBoots/
│   ├── manifest.json
│   ├── 1.0.0/
│   │   └── firmware.bin
│   ├── 1.0.1/
│   │   └── firmware.bin
│   ├── 1.1.0/
│   │   └── firmware.bin
│   └── ...
└── [other projects]/
```

### manifest.json Format

```json
{
  "project": "BootBoots",
  "versions": [
    {
      "version": "1.1.0",
      "timestamp": "2025-10-04T14:30:00+00:00",
      "firmware_path": "BootBoots/1.1.0/firmware.bin",
      "size": 1048576
    },
    {
      "version": "1.0.1",
      "timestamp": "2025-10-03T10:15:00+00:00",
      "firmware_path": "BootBoots/1.0.1/firmware.bin",
      "size": 1045678
    }
  ]
}
```

---

## Version Management

### Semantic Versioning

- **MAJOR** (X.0.0): Breaking changes, incompatible API changes
- **MINOR** (1.X.0): New features, backward-compatible
- **PATCH** (1.0.X): Bug fixes, security updates

### Version File Structure

The `include/version.h` file is auto-generated:

```cpp
#define FIRMWARE_VERSION "1.0.1"
#define BUILD_TIMESTAMP __DATE__ " " __TIME__
#define PROJECT_NAME "BootBoots"

#define VERSION_MAJOR 1
#define VERSION_MINOR 0
#define VERSION_PATCH 1

#define VERSION_STRING PROJECT_NAME " v" FIRMWARE_VERSION " (" BUILD_TIMESTAMP ")"
```

---

## Development Workflow

### 1. Make Code Changes
```bash
# Edit source files
vim src/main.cpp
```

### 2. Test Locally
```bash
# Build without uploading
python scripts/build_and_upload.py --build-only

# Flash directly via USB
pio run --target upload
```

### 3. Deploy to S3
```bash
# Build and upload with version bump
python scripts/build_and_upload.py --version-type patch
```

### 4. Deploy via Web Interface
1. Open web app at https://sandbox.nakomis.com
2. Navigate to "Firmware Manager"
3. Connect to device via Bluetooth
4. Select new version and deploy

---

## OTA Update Flow

```
┌─────────────────┐
│  Build Script   │
│  build_and_     │
│  upload.py      │
└────────┬────────┘
         │ Uploads
         ↓
┌─────────────────┐
│   S3 Bucket     │
│  bootboots-     │
│  firmware-      │
│  updates        │
└────────┬────────┘
         │ Signed URL
         ↓
┌─────────────────┐     Bluetooth      ┌─────────────────┐
│   Web App       │ ←─────────────────→ │   ESP32 Device  │
│  FirmwareManager│     OTA Command     │  BluetoothOTA   │
└─────────────────┘                     └────────┬────────┘
                                                 │ HTTP Download
                                                 ↓
                                        ┌─────────────────┐
                                        │   OTAUpdate     │
                                        │  Service        │
                                        └─────────────────┘
```

### Update Process

1. **Web App**: User selects firmware version
2. **Web App**: Generates S3 signed URL (1 hour expiration)
3. **Web App**: Sends `ota_update` command via Bluetooth with URL
4. **ESP32**: Receives command, validates URL
5. **ESP32**: Downloads firmware directly from S3 via HTTPS
6. **ESP32**: Writes to flash memory with progress updates
7. **ESP32**: Reboots with new firmware
8. **Web App**: Monitors progress via BLE notifications

---

## Troubleshooting

### Build Fails

**Problem**: `pio: command not found`
```bash
# Install PlatformIO
pip install platformio
```

**Problem**: Build errors with missing libraries
```bash
# Clean and rebuild
pio run --target clean
pio lib install
pio run
```

### Upload Fails

**Problem**: AWS credentials not configured
```bash
# Configure AWS CLI
aws configure
# Or set environment variables
export AWS_ACCESS_KEY_ID=your_key
export AWS_SECRET_ACCESS_KEY=your_secret
```

**Problem**: S3 bucket access denied
```bash
# Verify bucket exists
aws s3 ls s3://nakomis-firmware-updates

# Check IAM permissions
aws sts get-caller-identity
```

### OTA Update Fails

**Problem**: ESP32 can't connect to WiFi
- Check WiFi credentials in `secrets.h`
- Verify network is 2.4GHz (ESP32 doesn't support 5GHz)
- Check router allows ESP32 MAC address

**Problem**: Download from S3 fails
- Verify signed URL not expired (1 hour default)
- Check ESP32 serial monitor for HTTP errors
- Ensure device has internet access

**Problem**: Flash write fails
- Check available flash space
- Verify firmware size < available partition size
- Try power cycle and retry

---

## Advanced Options

### Manual PlatformIO Build

```bash
# Build only
pio run

# Upload via USB
pio run --target upload

# Clean build
pio run --target clean

# Build specific environment
pio run -e esp32cam
```

### Direct S3 Upload (without script)

```bash
# Build firmware first
pio run

# Upload to S3
aws s3 cp .pio/build/esp32cam/firmware.bin \
  s3://nakomis-firmware-updates/BootBoots/1.0.1/firmware.bin
```

### Testing OTA Locally

```bash
# Start local HTTP server
python -m http.server 8000

# In ESP32 code, use local URL
// const char* firmware_url = "http://192.168.1.100:8000/firmware.bin";
```

---

## Security Best Practices

1. **S3 Signed URLs**
   - URLs expire after 1 hour
   - Generated on-demand per update request
   - No permanent public access to firmware

2. **OTA Password**
   - Set in `secrets.h`
   - Required for network-based OTA (ArduinoOTA)
   - Use strong, unique password

3. **HTTPS Downloads**
   - ESP32 downloads firmware via HTTPS
   - Validates SSL certificates
   - Prevents man-in-the-middle attacks

4. **Bluetooth Security**
   - BLE communication uses characteristic-based access
   - Consider adding authentication in production

---

## CI/CD Integration

### GitHub Actions Example

```yaml
name: Build and Deploy Firmware

on:
  push:
    tags:
      - 'v*'

jobs:
  build:
    runs-on: ubuntu-latest
    steps:
      - uses: actions/checkout@v2

      - name: Set up Python
        uses: actions/setup-python@v2
        with:
          python-version: '3.9'

      - name: Install dependencies
        run: pip install -r requirements.txt

      - name: Build and upload firmware
        env:
          AWS_ACCESS_KEY_ID: ${{ secrets.AWS_ACCESS_KEY_ID }}
          AWS_SECRET_ACCESS_KEY: ${{ secrets.AWS_SECRET_ACCESS_KEY }}
        run: |
          cd embedded/catcam/cpp/catcam
          python scripts/build_and_upload.py --no-bump
```

---

## Monitoring & Logs

### ESP32 Serial Monitor

```bash
# Monitor with PlatformIO
pio device monitor

# Or with screen
screen /dev/cu.usbserial-* 115200
```

### Expected Log Output

```
=== BootBoots System Starting ===
[INFO] Initializing hardware...
[INFO] SD Logger initialized successfully
[INFO] WiFi connected successfully
[INFO] IP Address: 192.168.1.100
[INFO] Bluetooth Service initialized
[INFO] OTA Update service initialized
[INFO] Bluetooth OTA service initialized
[INFO] Bluetooth OTA enabled - remote updates via web interface
=== BootBoots System Ready ===
```

### S3 Access Logs

Enable S3 server access logging to track firmware downloads:

```bash
aws s3api put-bucket-logging \
  --bucket nakomis-firmware-updates \
  --bucket-logging-status file://logging.json
```

---

## Support & Resources

- **Project README**: See main project README.md
- **OTA System**: See README_OTA_SYSTEM.md in old.catcam
- **PlatformIO Docs**: https://docs.platformio.org
- **ESP32 OTA Docs**: https://docs.espressif.com/projects/esp-idf/en/latest/esp32/api-reference/system/ota.html

---

## Quick Reference

| Command | Action |
|---|---|
| `python scripts/build_and_upload.py` | Build + upload with patch bump |
| `--version-type minor` | Minor version bump |
| `--version-type major` | Major version bump |
| `--no-bump` | Use current version |
| `--build-only` | Build without S3 upload |
| `pio run` | Build firmware only |
| `pio run --target upload` | Flash via USB |
| `pio device monitor` | Open serial monitor |

**S3 Bucket**: `nakomis-firmware-updates`
**Project Name**: `BootBoots`
**Current Version**: Check `include/version.h`

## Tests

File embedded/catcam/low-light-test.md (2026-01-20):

# OV5640 Low Light Optimization Testing

Testing various camera settings to improve low-light performance on the ESP32-S3 with OV5640 sensor.

## Test Plan

| # | Setting | Change | Status | Result |
|---|---|---|---|---|
| 1 | Gain Ceiling | 0 → 6 (max) | ✅ Done | No improvement |
| 2 | Night Mode (AEC2) | 0 → 1 (enable) | ✅ Done | No improvement |
| 3 | AE Level | 0 → +2 | ✅ Done | No improvement |
| 4 | Exposure Value | 300 → 800 | ✅ Done | Slightly better, not good |
| 5 | Manual Gain | 0 → 15 | 🔄 Testing | - |
| 6 | Frame Size | UXGA → XGA | ⏳ Pending | - |
| 7 | JPEG Quality | 10 → 6 | ⏳ Pending | - |

## Test Details

### Test 1: Increase Gain Ceiling (0 → 6)
**Setting:** `s->set_gainceiling(s, (gainceiling_t)6)`

Allows auto-gain to amplify the signal much more in low light conditions.

**Result:** No improvement observed.

---

### Test 2: Enable Night Mode (AEC2)
**Setting:** `s->set_aec2(s, 1)`

Enables the OV5640's built-in night mode which automatically reduces frame rate in low light to allow longer exposures.

**Result:** No improvement observed.

---

### Test 3: Increase AE Level (0 → +2)
**Setting:** `s->set_ae_level(s, 2)`

Biases auto-exposure toward brighter images.

**Result:** No improvement observed.

---

### Test 4: Increase Exposure Value (300 → 800)
**Setting:** `s->set_aec_value(s, 800)`

Higher base exposure time (though auto-exposure may override).

**Result:** Slightly better, but not good.

---

### Test 5: Increase Manual Gain (0 → 15)
**Setting:** `s->set_agc_gain(s, 15)`

Manually set higher gain. Trade-off: more noise.

**Result:** Pending

---

### Test 6: Reduce Frame Size (UXGA → XGA)
**Setting:** `config.frame_size = FRAMESIZE_XGA` (1024x768)

Lower resolution = more light per pixel.

**Result:** Pending

---

### Test 7: Lower JPEG Quality Number (10 → 6)
**Setting:** `config.jpeg_quality = 6`

Preserves more detail (lower number = higher quality). Doesn't help with light but may preserve detail better in low-light images.

**Result:** Pending

---

## Notes

- All tests performed on ESP32-S3 with OV5640 camera
- Each test is done in isolation (reset to baseline before applying next change)
- Testing in consistent low-light indoor environment

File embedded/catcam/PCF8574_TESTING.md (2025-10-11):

# PCF8574 GPIO Expander - Testing Guide

## ⚠️ Pin Conflict with Serial/UART0

The PCF8574 uses GPIO1 (TX) and GPIO3 (RX) which are UART0 pins. This creates a conflict with USB serial communication.

**IMPORTANT**:
- **OTA Updates (Recommended)**: ✅ No disconnection needed - flash wirelessly via web interface
- **USB Serial Flashing**: ⚠️ You MUST physically disconnect the PCF8574 from GPIO1/GPIO3 before flashing
- **Serial Monitor**: Will NOT work once PCF8574 is connected (use BLE or SD logs instead)

## Hardware Setup

### PCF8574 Pin Connections

| PCF8574 Pin | ESP32-CAM Pin | Function |
|---|---|---|
| VCC | 3.3V | Power |
| GND | GND | Ground |
| SDA | GPIO1 (U0TXD) | I2C Data |
| SCL | GPIO3 (U0RXD) | I2C Clock |
| A0 | GND | Address bit 0 (address = 0x20) |
| A1 | GND | Address bit 1 |
| A2 | GND | Address bit 2 |

### Pull-up Resistors ✅

- **Internal pull-ups enabled** - No external resistors required! ✅
- The ESP32 enables ~45kΩ internal pull-ups on GPIO1 and GPIO3 via software
- This is configured automatically in `initializeHardware()` using `pinMode(pin, INPUT_PULLUP)`
- **Optional**: Add external 4.7kΩ pull-ups for more reliable I2C communication in noisy environments
  - Only needed for long wire runs (>10cm) or high-speed I2C (>100kHz)
  - Not required for this project

### PCF8574 GPIO Pins (P0-P7)

| Pin | Function | Test Output |
|-----|---|---|
| P0 | Atomizer Control | Not used in Phase 1 |
| P1 | Flash LED | **Blinking in test** |
| P2 | Pressure Sensor | Not used in Phase 1 |
| P3-P7 | Spare | Future expansion |

## Flashing Procedure

### Option 1: OTA Update (RECOMMENDED - No Disconnection Required) ✅

**This is the preferred method once PCF8574 is connected:**

1. **Build and upload firmware**:
   ```bash
   python scripts/build_and_upload.py --version-type patch
   # or
   python scripts/build_and_upload.py --no-bump
   ```

2. **Deploy via web interface**:
   - Open web app → Firmware Manager
   - Connect to device via Bluetooth
   - Select the new firmware version
   - Click "Deploy Firmware Update"
   - Monitor progress via BLE

3. **Device updates automatically**:
   - Downloads firmware from S3 via WiFi
   - Reboots into bootloader
   - Flashes new firmware
   - Reboots with new version
   - **PCF8574 remains connected throughout** ✅

### Option 2: USB Serial Flashing (Only if OTA not available) ⚠️

**Only use this method for initial setup or if OTA fails:**

**Step 1: Disconnect PCF8574**
1. Physically disconnect PCF8574 SDA wire from GPIO1
2. Physically disconnect PCF8574 SCL wire from GPIO3
3. Leave power and ground connected if convenient, or disconnect entirely

**Step 2: Flash Firmware**
```bash
pio run --target upload --upload-port /dev/cu.usbserial-*
```

**Step 3: Reconnect PCF8574**
1. Reconnect SDA wire to GPIO1
2. Reconnect SCL wire to GPIO3
3. Power cycle the ESP32-CAM (unplug and replug USB)

## Testing Procedure

### Phase 1: Initialization Test

**Expected behavior after boot**:
1. ESP32-CAM boots normally
2. I2C initializes on GPIO1/GPIO3 at 100kHz
3. PCF8574 self-test runs (writes/reads test patterns)
4. System logs show PCF8574 initialization success

**Check via BLE Status**:
- Connect to device via web interface (Bluetooth tab)
- Look for "PCF8574 Manager initialized successfully" message
- System status should show `PCF8574: OK`

**Check via Web Interface Logs** (RECOMMENDED):
- Open web app → Bluetooth tab
- Connect to device
- Click "Retrieve Logs" button
- Logs are fetched via BLE (chunked transfer)
- Search for "PCF8574" in the log viewer

**Alternative - SD Card Logs** (if web interface unavailable):
```bash
# After test run, mount SD card and check logs
grep "PCF8574" /Volumes/FAT32_Mount/logs/*.log
```

Expected log entries:
```
[INFO] I2C initialized on GPIO1 (SDA) and GPIO3 (SCL)
[INFO] PCF8574Manager initializing on I2C address 0x20 (SDA: 1, SCL: 3)
[INFO] PCF8574: Performing self-test...
[INFO] PCF8574: Self-test completed successfully
[INFO] PCF8574Manager initialized successfully (SAFETY MODE: Emergency shutdown capable)
[INFO] PCF8574 Manager initialized - 8 GPIO pins available
```

### Phase 2: LED Blink Test

**Test code** (already integrated in main.cpp):
- Flash LED (P1) blinks every 2 seconds
- LED toggles ON/OFF continuously

**Visual verification**:
1. Connect LED to PCF8574 P1 with appropriate resistor (~330Ω)
2. LED should blink every 2 seconds
3. Observe for at least 30 seconds to confirm consistent blinking

**Log verification** (via web interface):
- Web app → Bluetooth tab → Retrieve Logs
- Search for "Flash LED" in log viewer
- Should see entries every 2 seconds

**Alternative** (SD card):
```bash
grep "Flash LED" /Volumes/FAT32_Mount/logs/*.log
```

Expected log entries (every 2 seconds):
```
[DEBUG] PCF8574 Flash LED (P1): ON
[DEBUG] PCF8574 Flash LED (P1): OFF
[DEBUG] PCF8574 Flash LED (P1): ON
...
```

### Phase 3: Emergency Shutdown Test

**Manual test** (add to main.cpp if needed):
```cpp
// Test emergency shutdown
pcfManager->emergencyShutdown();
// All pins should go LOW immediately
```

Expected behavior:
- All PCF8574 outputs forced to LOW
- Emergency mode flag set
- Future pin control blocked until reset

## Troubleshooting

### PCF8574 Not Detected

**Symptom**: Logs show "PCF8574 device not found at address 0x20"

**Solutions**:
1. Check I2C wiring (GPIO1=SDA, GPIO3=SCL)
2. Verify PCF8574 power (3.3V, not 5V)
3. Check PCF8574 address jumpers (A0, A1, A2 all to GND = 0x20)
4. **Optional**: Add external 4.7kΩ pull-ups if wires are long (>10cm)
   - Internal pull-ups (~45kΩ) are usually sufficient
   - External pull-ups help with long wires or noisy environments
5. Try I2C scanner code to detect address

### LED Not Blinking

**Symptom**: PCF8574 initializes but LED doesn't blink

**Solutions**:
1. Verify LED polarity (anode to P1, cathode to GND via resistor)
2. Check resistor value (~330Ω for standard LED)
3. Confirm P1 pin number (should be pin 1 on PCF8574)
4. Check logs for "Flash LED" debug messages
5. Measure voltage on P1 with multimeter (should toggle between 0V and 3.3V)

### Serial Monitor Not Working

**This is expected!** GPIO1/GPIO3 are used for I2C, not UART0.

**Alternative debugging**:
- Use BLE Bluetooth interface via web app
- Read SD card logs after test run
- Use GPIO33 onboard LED for visual feedback (if needed)

## Debugging Without Serial Monitor

Since Serial Monitor won't work with PCF8574 connected, use these methods:

### 1. Web Interface Logs (RECOMMENDED) ✅
- Connect via web interface → Bluetooth tab
- View real-time system status
- Click "Retrieve Logs" to fetch logs via BLE chunked transfer
- Search/filter logs directly in browser
- **No need to remove SD card!**

### 2. BLE Status Messages
- Real-time status updates every 10 seconds
- Shows PCF8574 initialization status
- Displays system health

### 3. SD Card Logging (Backup/Alternative)
- All events logged to `/logs/` on SD card
- Only needed if web interface unavailable
- Remove SD card and read logs on computer

### 4. LED Indicators
- PCF8574 P1 blinks = system working
- Onboard LED (GPIO33) available if needed

## Success Criteria

PCF8574 Phase 1 is complete when:
- [ ] PCF8574 initializes successfully
- [ ] Self-test passes
- [ ] P1 LED blinks every 2 seconds
- [ ] BLE status shows `PCF8574: OK`
- [ ] SD logs show successful initialization
- [ ] No I2C errors in logs
- [ ] Emergency shutdown tested (optional for Phase 1)

## Next Steps

After PCF8574 Phase 1 success:
1. Update PLAN.md with test results
2. Remove LED blink test from loop() (or comment out)
3. Proceed to Phase 2: Camera Module integration
4. Keep PCF8574 connected for future atomizer control (Phase 5)

## Wiring Diagram

```
ESP32-CAM                  PCF8574
┌────────────┐            ┌────────────┐
│            │            │            │
│  GPIO1 (TX)├────────────┤ SDA        │
│  GPIO3 (RX)├────────────┤ SCL        │
│            │            │            │
│   3.3V     ├────────────┤ VCC        │
│   GND      ├────────────┤ GND        │
│            │            │            │
└────────────┘            │ A0─────GND │
                          │ A1─────GND │
                          │ A2─────GND │
                          │            │
                          │ P0         │
                          │ P1─────[LED]──[330Ω]──GND
                          │ P2         │
                          │ P3-P7      │
                          └────────────┘

Internal pull-ups enabled via software (automatic):
   ESP32 GPIO1 (~45kΩ internal pull-up to 3.3V) ✅
   ESP32 GPIO3 (~45kΩ internal pull-up to 3.3V) ✅

Optional external pull-ups (only if needed for long wires):
   3.3V ──[4.7kΩ]── SDA
   3.3V ──[4.7kΩ]── SCL
```

## Important Notes

1. **Use OTA for all updates** once PCF8574 is wired - no disconnection needed! ✅
2. **Only disconnect for USB serial flashing** (initial setup or emergency recovery)
3. **Serial Monitor won't work** with PCF8574 connected - use BLE or SD logs instead
4. **Test LED should blink** every 2 seconds if working
5. **Emergency shutdown** is available for safety testing

## Reference

- PCF8574 Datasheet: NXP PCF8574/PCF8574A
- I2C Address: 0x20 (A0=A1=A2=GND)
- I2C Speed: 100kHz (set in code for reliability)
- Pull-up Resistors: 4.7kΩ recommended
- Supply Voltage: 3.3V (ESP32 compatible)

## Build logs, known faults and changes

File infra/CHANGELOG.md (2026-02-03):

# Infrastructure Changelog

## 2025-10-11 - Firmware Cleanup Lambda

### Added

**New Stack: `BootBootsFirmwareCleanupStack`**
- Automated S3 firmware version cleanup
- Keeps only the 3 most recent versions per project
- Automatically updates manifest.json files

**Components:**
- Lambda function: `FirmwareCleanupLambda`
  - Runtime: Node.js 22.x
  - Timeout: 60 seconds
  - Memory: 256 MB
  - Trigger: S3 ObjectCreated events for `firmware.bin` files

- S3 Event Notification
  - Configured automatically via `bucket.addEventNotification()`
  - Triggers on: `s3.EventType.OBJECT_CREATED`
  - Filter: Suffix `firmware.bin`
  - Bucket: `nakomis-firmware-updates`

- CloudWatch Logs
  - Log group: `/aws/lambda/FirmwareCleanupLambda`
  - Retention: 6 months

**IAM Permissions:**
- S3: ListBucket, GetObject, DeleteObject, PutObject
- Lambda invoke permission (automatically granted via `LambdaDestination`)

### Key Features

1. **Semantic Version Sorting**
   - Properly handles version numbers (1.10.0 > 1.9.0)
   - Newest versions kept, oldest deleted

2. **Multi-Project Support**
   - Works for any project following `{Project}/{Version}/firmware.bin` pattern
   - Automatically detects project name from S3 key

3. **Automatic Manifest Updates**
   - Rebuilds manifest.json after cleanup
   - Includes version, timestamp, path, and size metadata

4. **Fully Automated Setup**
   - S3 event notification configured via `bucket.addEventNotification()`
   - Lambda permissions automatically granted via `LambdaDestination`
   - No manual AWS console configuration required

### Changed

**Upload Script Simplified:**
- Removed `create_version_manifest()` method from `build_and_upload.py`
- Manifest updates now handled automatically by Lambda
- Reduced code complexity by ~50 lines

### Files Created

```
infra/
├── lambda/
│   └── firmware-cleanup/
│       ├── src/
│       │   └── handler.ts          # Lambda function handler
│       ├── package.json             # Dependencies
│       ├── tsconfig.json            # TypeScript config
│       └── README.md                # Lambda documentation
├── lib/
│   └── firmware-cleanup-stack.ts   # CDK stack definition
├── DEPLOYMENT.md                    # Deployment guide
└── CHANGELOG.md                     # This file

embedded/catcam/cpp/catcam/scripts/
└── build_and_upload.py             # Modified (simplified)
```

### Files Modified

```
infra/
├── bin/infra.ts                     # Added new stack

embedded/catcam/cpp/catcam/scripts/
└── build_and_upload.py              # Removed manifest logic
```

### Deployment

```bash
cd /Users/martinmu_1/repos/nakomis/bootboots/infra
npm install
export AWS_PROFILE=nakom.is-sandbox
cdk deploy BootBootsFirmwareCleanupStack
```

### Benefits

1. **Cost Savings:** Reduces S3 storage costs by automatically deleting old versions
2. **Automation:** No manual S3 management required
3. **Simplified Code:** Upload script is simpler and more focused
4. **Consistent State:** Manifest always matches S3 contents
5. **Multi-Project:** Works for all projects in the bucket

### Technical Implementation

**S3 Event Notification via addEventNotification:**
```typescript
firmwareBucket.addEventNotification(
  s3.EventType.OBJECT_CREATED,
  new s3n.LambdaDestination(cleanupLambda),
  { suffix: 'firmware.bin' }
);
```

Since CDK v2, `addEventNotification()` works on imported buckets (from `Bucket.fromBucketName()`). The `LambdaDestination` automatically:
- Grants S3 permission to invoke the Lambda
- Configures the S3 bucket notification
- Handles cleanup on stack deletion

### Testing

1. Upload firmware: `python scripts/build_and_upload.py`
2. Check CloudWatch Logs: `aws logs tail /aws/lambda/FirmwareCleanupLambda --follow`
3. Verify manifest: `aws s3 cp s3://nakomis-firmware-updates/BootBoots/manifest.json -`
4. List S3 files: `aws s3 ls s3://nakomis-firmware-updates/BootBoots/ --recursive`

Should see only 3 firmware versions retained.

### Migration Notes

**Before this change:**
- Upload script manually updated manifest.json
- Old firmware versions accumulated in S3
- Manual cleanup required

**After this change:**
- Lambda automatically updates manifest.json
- Only 3 most recent versions kept
- Fully automated cleanup

**No migration required** - Next firmware upload will trigger automatic cleanup of existing old versions.

### Known Limitations

1. Requires firmware to follow `{Project}/{Version}/firmware.bin` naming pattern
2. Version must be semantic (MAJOR.MINOR.PATCH)
3. S3 bucket must allow PutBucketNotification API calls

### Future Enhancements

Potential improvements:
- Configurable retention (3 versions is hardcoded)
- Support for pre-release versions (e.g., 1.0.0-beta)
- Notification on cleanup (SNS/email)
- Metrics/dashboards for cleanup activity

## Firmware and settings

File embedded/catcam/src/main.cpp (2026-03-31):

#include <Arduino.h>
#include <SD_MMC.h>
#include <SDLogger.h>
#include <esp_ota_ops.h>
#include <esp_partition.h>
#include <Preferences.h>

#include "SystemState.h"
#include "SystemManager.h"
#include "PCF8574Manager.h"
#include "LedController.h"
#include "InputManager.h"
#include "CaptureController.h"
#include "MotionDetector.h"
#include "DeterrentController.h"
#include "BluetoothService.h"
#include "CommandDispatcher.h"
#include "Camera.h"
#include "version.h"
#include "secrets.h"

#ifndef OTA_PASSWORD
#define OTA_PASSWORD "bootboots-ota-2025"
#endif

// Board-specific pin configuration
#ifdef ESP32S3_CAM
// ESP32-S3 CAM: Dedicated I2C pins (not shared with UART)
#define I2C_SDA 47               // GPIO4 - SDA
#define I2C_SCL 21               // GPIO5 - SCL
#define BOARD_NAME "ESP32-S3-CAM"
#else
// Original ESP32-CAM: I2C on UART0 pins
#define I2C_SDA 47               // GPIO1 (U0TXD) - SDA
#define I2C_SCL 21               // GPIO3 (U0RXD) - SCL
#define BOARD_NAME "ESP32-CAM"
#endif

#define PCF8574_ADDRESS 0x20    // I2C address for PCF8574

// BOOT button for user input (triggers photo capture)
#define BOOT_BUTTON_PIN 0       // GPIO0 - BOOT button (LOW when pressed)

// Image storage settings
#define IMAGES_DIR "/images"
#define MAX_IMAGES_TO_KEEP 20

// AWS Auth configuration
const char* AWS_ROLE_ALIAS = "BootBootsRoleAlias";
const char* API_HOST = "api.bootboots.sandbox.nakomis.com";
const char* API_PATH = "/infer";

// Global system components
SystemState systemState;
SystemManager systemManager;
LedController ledController;
InputManager inputManager;
Preferences preferences;

// Function declarations
bool isBootButtonPressed();
void saveTrainingMode(bool enabled);
void loadCameraSettings();
void saveCameraSetting(const String& setting, int value);

// Wrapper for BluetoothService extern - delegates to CaptureController
String captureAndPostPhoto();

void setup() {
    Serial.begin(115200);
    delay(500);  // Give serial time to initialize
    Serial.println("\n\n=== CATCAM STARTING ===");
    Serial.printf("Version: %s\n", FIRMWARE_VERSION);
    Serial.flush();

    // CRITICAL: Set boot partition to factory so bootloader runs on next reboot
    // This ensures the bootloader can check for pending OTA updates from SD card
    const esp_partition_t* factory = esp_partition_find_first(
        ESP_PARTITION_TYPE_APP,
        ESP_PARTITION_SUBTYPE_APP_FACTORY,
        NULL
    );

    if (factory != NULL) {
        const esp_partition_t* boot_partition = esp_ota_get_boot_partition();

        // Only set boot partition if it's not already pointing to factory
        if (boot_partition != factory) {
            esp_err_t err = esp_ota_set_boot_partition(factory);
            if (err == ESP_OK) {
                Serial.println("[CATCAM] Set boot partition to factory for next reboot");
            }
            else {
                Serial.printf("[CATCAM] WARNING: Failed to set boot partition: %s\n", esp_err_to_name(err));
            }
        }
    }
    else {
        Serial.println("[CATCAM] WARNING: Factory partition not found - bootloader won't run on reboot");
    }

    // Initialize SDLogger for normal operation (after OTA check)
    Serial.println("Initializing SDLogger...");
    Serial.flush();
    bool sdLoggerOk = SDLogger::getInstance().init("/logs");
    Serial.printf("SDLogger init result: %s\n", sdLoggerOk ? "OK" : "FAILED");
    Serial.flush();
    SDLogger::getInstance().setLogLevel(LOG_DEBUG);
    SDLogger::getInstance().infof("=== BootBoots System Starting (%s) ===", BOARD_NAME);

    // Record system start time
    systemState.systemStartTime = millis();

    // Load training mode and deterrent settings from NVS
    preferences.begin("bootboots", false);
    systemState.trainingMode = preferences.getBool("trainingMode", false);
    systemState.triggerThresh = preferences.getFloat("triggerThresh", 0.80f);
    systemState.dryRun = preferences.getBool("dryRun", false);
    systemState.claudeInfer = preferences.getBool("claudeInfer", false);
    SDLogger::getInstance().infof("Training mode loaded from NVS: %s", systemState.trainingMode ? "ON" : "OFF");
    SDLogger::getInstance().infof("Trigger threshold loaded from NVS: %.2f", systemState.triggerThresh);
    SDLogger::getInstance().infof("Dry-run mode loaded from NVS: %s", systemState.dryRun ? "ON" : "OFF");
    SDLogger::getInstance().infof("Claude inference loaded from NVS: %s", systemState.claudeInfer ? "ON" : "OFF");
    preferences.end();

    // Load camera settings from NVS
    loadCameraSettings();

    // Configure SystemManager
    SystemManager::Config config = {
        .i2cSDA = I2C_SDA,
        .i2cSCL = I2C_SCL,
        .pcf8574Address = PCF8574_ADDRESS,
        .bootButtonPin = BOOT_BUTTON_PIN,
        .debounceMs = 50,
        .imagesDir = IMAGES_DIR,
        .maxImagesToKeep = MAX_IMAGES_TO_KEEP,
        .deviceName = "BootBoots-CatCam",
        .awsRegion = "eu-west-2",
        .awsRoleAlias = AWS_ROLE_ALIAS,
        .apiHost = API_HOST,
        .apiPath = API_PATH
    };

    // Initialize hardware first
    systemManager.initHardware(config, systemState, inputManager);

    // Initialize all system components
    systemManager.initComponents(config, systemState, ledController, inputManager);

    // Register callbacks with CommandDispatcher (handles commands from BLE and MQTT)
    CommandDispatcher* dispatcher = systemManager.getCommandDispatcher();
    if (dispatcher) {
        dispatcher->setTrainingModeCallback(saveTrainingMode);
        dispatcher->setCameraSettingCallback(saveCameraSetting);

        // set_trigger_threshold {"value": 0.85} — update Boots confidence threshold
        dispatcher->registerHandler("set_trigger_threshold", [](CommandContext& ctx) {
            float value = ctx.request["value"] | 0.80f;
            if (value < 0.0f) value = 0.0f;
            if (value > 1.0f) value = 1.0f;
            systemState.triggerThresh = value;
            preferences.begin("bootboots", false);
            preferences.putFloat("triggerThresh", value);
            preferences.end();
            SDLogger::getInstance().infof("Trigger threshold set to %.2f (%.0f%%)", value, value * 100.0f);

            DynamicJsonDocument response(256);
            response["type"] = "setting_updated";
            response["setting"] = "trigger_threshold";
            response["value"] = value;
            String responseStr;
            serializeJson(response, responseStr);
            ctx.sender->sendResponse(responseStr);
            return true;
        });

        // set_dry_run {"enabled": true} — enable/disable dry-run mode
        dispatcher->registerHandler("set_dry_run", [](CommandContext& ctx) {
            bool value = ctx.request["enabled"] | false;
            systemState.dryRun = value;
            preferences.begin("bootboots", false);
            preferences.putBool("dryRun", value);
            preferences.end();
            SDLogger::getInstance().infof("Dry-run mode %s", value ? "ON" : "OFF");

            DynamicJsonDocument response(256);
            response["type"] = "setting_updated";
            response["setting"] = "dry_run";
            response["value"] = value;
            String responseStr;
            serializeJson(response, responseStr);
            ctx.sender->sendResponse(responseStr);
            return true;
        });

        // set_claude_infer {"enabled": true} — enable/disable parallel Claude vision inference
        dispatcher->registerHandler("set_claude_infer", [](CommandContext& ctx) {
            bool value = ctx.request["enabled"] | false;
            systemState.claudeInfer = value;
            preferences.begin("bootboots", false);
            preferences.putBool("claudeInfer", value);
            preferences.end();
            SDLogger::getInstance().infof("Claude inference %s", value ? "ON" : "OFF");

            DynamicJsonDocument response(256);
            response["type"] = "setting_updated";
            response["setting"] = "claude_infer";
            response["value"] = value;
            String responseStr;
            serializeJson(response, responseStr);
            ctx.sender->sendResponse(responseStr);
            return true;
        });

        // set_peripheral {"peripheral": "flash_led"|"led_strip"|"spray", "state": true|false}
        // Direct peripheral control for hardware testing via the test UI.
        dispatcher->registerHandler("set_peripheral", [](CommandContext& ctx) {
            String peripheral = ctx.request["peripheral"] | "";
            bool state = ctx.request["state"] | false;

            if (peripheral.isEmpty()) {
                DynamicJsonDocument errDoc(128);
                errDoc["type"] = "error";
                errDoc["message"] = "Missing 'peripheral' field";
                String errStr; serializeJson(errDoc, errStr);
                ctx.sender->sendResponse(errStr);
                return false;
            }

            PCF8574Manager* pcf = systemManager.getPcfManager();
            if (!pcf || !systemState.pcf8574Ready) {
                DynamicJsonDocument errDoc(128);
                errDoc["type"] = "error";
                errDoc["message"] = "PCF8574 not available";
                String errStr; serializeJson(errDoc, errStr);
                ctx.sender->sendResponse(errStr);
                return false;
            }

            bool ok = false;
            if (peripheral == "flash_led") {
                ok = pcf->setFlashLED(state);
                if (ok) systemState.flashLedOn = state;
            } else if (peripheral == "led_strip") {
                // Control both LED strip channels together
                bool ok1 = pcf->setPinState(PCF8574Manager::LED_STRIP_1_PIN, state);
                bool ok2 = pcf->setPinState(PCF8574Manager::LED_STRIP_2_PIN, state);
                ok = ok1 && ok2;
                if (ok) systemState.ledStripOn = state;
            } else if (peripheral == "spray") {
                if (state) {
                    ok = pcf->setAtomizerState(true);
                    if (ok) {
                        systemState.sprayOn = true;
                        systemState.sprayAutoOffAt = millis() + 5000;
                    }
                } else {
                    ok = pcf->setAtomizerState(false);
                    if (ok) {
                        systemState.sprayOn = false;
                        systemState.sprayAutoOffAt = 0;
                    }
                }
            } else {
                DynamicJsonDocument errDoc(128);
                errDoc["type"] = "error";
                errDoc["message"] = "Unknown peripheral: " + peripheral;
                String errStr; serializeJson(errDoc, errStr);
                ctx.sender->sendResponse(errStr);
                return false;
            }

            SDLogger::getInstance().infof("Peripheral '%s' set %s via %s",
                peripheral.c_str(), state ? "ON" : "OFF", ctx.sender->getName());

            DynamicJsonDocument response(256);
            response["type"] = "peripheral_updated";
            response["peripheral"] = peripheral;
            response["state"] = state;
            response["ok"] = ok;
            String responseStr;
            serializeJson(response, responseStr);
            ctx.sender->sendResponse(responseStr);
            return true;
        });

        // simulate_detection — trigger full deterrent sequence (LEDs, video, upload) with a
        // synthetic Boots result. Does not capture a photo or call SageMaker. Respects dryRun.
        dispatcher->registerHandler("simulate_detection", [](CommandContext& ctx) {
            DeterrentController* dc = systemManager.getDeterrentController();
            if (!dc) {
                DynamicJsonDocument errDoc(128);
                errDoc["type"] = "error";
                errDoc["message"] = "Deterrent controller not available";
                String errStr; serializeJson(errDoc, errStr);
                ctx.sender->sendResponse(errStr);
                return false;
            }

            SDLogger::getInstance().infof("=== Simulating Boots Detection ===");

            // Acknowledge before blocking so the UI can show in-progress state
            DynamicJsonDocument startDoc(128);
            startDoc["type"] = "simulation_started";
            String startStr; serializeJson(startDoc, startStr);
            ctx.sender->sendResponse(startStr);

            systemState.deterrentActivationCount++;
            systemState.bootsDetections++;
            dc->activate(systemState, systemState.dryRun);  // BLOCKING ~10s

            DynamicJsonDocument doneDoc(128);
            doneDoc["type"] = "simulation_complete";
            String doneStr; serializeJson(doneDoc, doneStr);
            ctx.sender->sendResponse(doneStr);
            return true;
        });
    }

    // Sync training mode to capture controller
    CaptureController* captureController = systemManager.getCaptureController();
    if (captureController) {
        captureController->setTrainingMode(systemState.trainingMode);
    }

    // Mark system as initialized
    systemState.initialized = true;

    SDLogger::getInstance().infof("=== BootBoots System Ready ===");
    SDLogger::getInstance().info(BANNER);

    // Log system startup
    if (systemState.sdCardReady) {
        SDLogger::getInstance().infof("%s system v%s (%s) initialized successfully", PROJECT_NAME, FIRMWARE_VERSION, BUILD_TIMESTAMP);
        SDLogger::getInstance().infof("System Status - Camera: %s, WiFi: %s, I2C: %s, PCF8574: %s, Atomizer: %s",
            systemState.cameraReady ? "OK" : "FAIL",
            systemState.wifiConnected ? "OK" : "FAIL",
            systemState.i2cReady ? "OK" : "FAIL",
            systemState.pcf8574Ready ? "OK" : "FAIL",
            systemState.atomizerEnabled ? "ON" : "OFF");
    }
}

void loop() {
    // Update input manager (polls button state)
    inputManager.update();

    // Check for BOOT button press to record video
    if (inputManager.wasBootButtonJustPressed()) {
        SDLogger::getInstance().infof("BOOT button pressed - recording video");
        CaptureController* captureController = systemManager.getCaptureController();
        if (captureController) {
            captureController->recordVideo();
        }
    }

    // Check for PIR motion detection
    MotionDetector* motionDetector = systemManager.getMotionDetector();
    if (motionDetector && motionDetector->wasMotionDetected()) {
        SDLogger::getInstance().infof("PIR motion detected");
        systemState.motionTriggerCount++;

        CaptureController* captureController = systemManager.getCaptureController();
        DeterrentController* deterrentController = systemManager.getDeterrentController();

        if (captureController) {
            // Training mode: capture photo without inference/deterrent
            if (systemState.trainingMode) {
                SDLogger::getInstance().infof("Training mode: capturing photo without inference");
                captureController->captureTrainingPhoto();
            }
            // Normal mode: capture photo and run inference with deterrent
            else if (deterrentController) {
                // Capture photo and run inference
                DetectionResult result = captureController->captureAndDetect(systemState.claudeInfer);
                if (result.success && deterrentController->shouldActivate(result, systemState.triggerThresh)) {
                    SDLogger::getInstance().criticalf("Boots detected (%.1f%%) - activating deterrent! (dryRun=%s)",
                        result.confidence * 100.0f, systemState.dryRun ? "ON" : "OFF");
                    systemState.deterrentActivationCount++;
                    systemState.bootsDetections++;
                    deterrentController->activate(systemState, systemState.dryRun);  // BLOCKING ~10s
                } else if (result.success) {
                    systemState.totalDetections++;
                    if (result.detectedIndex != DeterrentController::BOOTS_INDEX) {
                        systemState.falsePositivesAvoided++;
                    }
                }
            }
        }
    }

    // Poll PIR sensor state so the BLE status broadcast reflects live readings
    {
        MotionDetector* motionDetector = systemManager.getMotionDetector();
        if (motionDetector) {
            systemState.pirActive = motionDetector->readRawState();
        }
    }

    // Auto-off for spray after 5 seconds
    if (systemState.sprayOn && systemState.sprayAutoOffAt > 0 && millis() >= systemState.sprayAutoOffAt) {
        PCF8574Manager* pcf = systemManager.getPcfManager();
        if (pcf) {
            pcf->setAtomizerState(false);
        }
        systemState.sprayOn = false;
        systemState.sprayAutoOffAt = 0;
        SDLogger::getInstance().infof("Spray auto-off after 5s");
    }

    // Handle Bluetooth, OTA, and WiFi status
    systemManager.update(systemState);

    // PCF8574 heartbeat LED
    systemManager.blinkPcfLed(systemState);

    delay(100);  // Shorter delay for responsive button handling
}

// Check if BOOT button is pressed (delegates to InputManager)
// Used as callback by CaptureController for cancel checks
bool isBootButtonPressed() {
    return inputManager.isBootButtonPressed();
}

// Wrapper function for BluetoothService extern - delegates to CaptureController
String captureAndPostPhoto() {
    CaptureController* captureController = systemManager.getCaptureController();
    if (captureController) {
        // Use training mode capture if training mode is enabled
        if (systemState.trainingMode) {
            return captureController->captureTrainingPhoto();
        }
        return captureController->capturePhoto();
    }
    SDLogger::getInstance().errorf("CaptureController not initialized");
    return "";
}

// Save training mode to NVS
void saveTrainingMode(bool enabled) {
    preferences.begin("bootboots", false);
    preferences.putBool("trainingMode", enabled);
    preferences.end();
    SDLogger::getInstance().infof("Training mode saved to NVS: %s", enabled ? "ON" : "OFF");

    // Also update capture controller
    CaptureController* captureController = systemManager.getCaptureController();
    if (captureController) {
        captureController->setTrainingMode(enabled);
    }
}

// Load camera settings from NVS
void loadCameraSettings() {
    CameraSettings& cs = systemState.cameraSettings;
    if (!preferences.begin("bootboots", true)) {  // read-only
        SDLogger::getInstance().errorf("Failed to open NVS namespace 'bootboots' for reading");
        return;
    }

    cs.frameSize = preferences.getInt("camFrmSize", cs.frameSize);
    cs.jpegQuality = preferences.getInt("camJpgQual", cs.jpegQuality);
    cs.fbCount = preferences.getInt("camFbCount", cs.fbCount);
    cs.brightness = preferences.getInt("camBright", cs.brightness);
    cs.contrast = preferences.getInt("camContrast", cs.contrast);
    cs.saturation = preferences.getInt("camSat", cs.saturation);
    cs.specialEffect = preferences.getInt("camEffect", cs.specialEffect);
    cs.whiteBalance = preferences.getBool("camWB", cs.whiteBalance);
    cs.awbGain = preferences.getBool("camAWBGain", cs.awbGain);
    cs.wbMode = preferences.getInt("camWBMode", cs.wbMode);
    cs.exposureCtrl = preferences.getBool("camExpCtrl", cs.exposureCtrl);
    cs.aec2 = preferences.getBool("camAEC2", cs.aec2);
    cs.aeLevel = preferences.getInt("camAELevel", cs.aeLevel);
    cs.aecValue = preferences.getInt("camAECVal", cs.aecValue);
    cs.gainCtrl = preferences.getBool("camGainCtrl", cs.gainCtrl);
    cs.agcGain = preferences.getInt("camAGCGain", cs.agcGain);
    cs.gainCeiling = preferences.getInt("camGainCeil", cs.gainCeiling);
    cs.bpc = preferences.getBool("camBPC", cs.bpc);
    cs.wpc = preferences.getBool("camWPC", cs.wpc);
    cs.rawGma = preferences.getBool("camGamma", cs.rawGma);
    cs.lenc = preferences.getBool("camLenc", cs.lenc);
    cs.hmirror = preferences.getBool("camHMirror", cs.hmirror);
    cs.vflip = preferences.getBool("camVFlip", cs.vflip);
    cs.dcw = preferences.getBool("camDCW", cs.dcw);
    cs.colorbar = preferences.getBool("camColorbar", cs.colorbar);
    cs.ledDelayMillis = preferences.getInt("ledDelayMillis", cs.ledDelayMillis);

    preferences.end();
    SDLogger::getInstance().infof("Camera settings loaded from NVS (ledDelayMillis=%d)", cs.ledDelayMillis);
}
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

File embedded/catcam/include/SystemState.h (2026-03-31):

#ifndef CATCAM_SYSTEMSTATE_H
#define CATCAM_SYSTEMSTATE_H

// Camera sensor settings - synced via BLE and persisted to NVS
struct CameraSettings {
    int frameSize = 13;        // framesize_t enum: 5=QVGA, 8=VGA, 9=SVGA, 10=XGA, 11=HD, 12=SXGA, 13=UXGA
    int jpegQuality = 10;      // 0-63 (lower = better quality, more data)
    int fbCount = 2;           // 1-3 frame buffers (requires PSRAM for >1)
    int brightness = 0;        // -2 to 2
    int contrast = 0;          // -2 to 2
    int saturation = 0;        // -2 to 2
    int specialEffect = 0;     // 0=None, 1=Negative, 2=Grayscale, 3=Red, 4=Green, 5=Blue, 6=Sepia
    bool whiteBalance = true;
    bool awbGain = true;
    int wbMode = 0;            // 0=Auto, 1=Sunny, 2=Cloudy, 3=Office, 4=Home
    bool exposureCtrl = true;
    bool aec2 = false;
    int aeLevel = -2;          // -2 to 2
    int aecValue = 300;        // 0 to 1200
    bool gainCtrl = true;
    int agcGain = 15;          // 0 to 30
    int gainCeiling = 0;       // 0 to 6
    bool bpc = false;
    bool wpc = true;
    bool rawGma = true;
    bool lenc = true;
    bool hmirror = false;
    bool vflip = false;
    bool dcw = true;
    bool colorbar = false;
    int ledDelayMillis = 100;
};

// SystemState struct definition - shared between main.cpp and BluetoothService
struct SystemState {
    bool initialized = false;
    bool cameraReady = false;
    bool wifiConnected = false;
    bool mqttConnected = false;
    bool sdCardReady = false;
    bool i2cReady = false;
    bool pcf8574Ready = false;
    bool atomizerEnabled = false;
    unsigned long lastDetection = 0;
    unsigned long lastStatusReport = 0;
    unsigned long systemStartTime = 0;
    int totalDetections = 0;
    int bootsDetections = 0;
    int falsePositivesAvoided = 0;
    int atomizerActivations = 0;

    // Motion detection tracking
    int motionTriggerCount = 0;         // Total PIR motion events detected
    int deterrentActivationCount = 0;   // Times deterrent was activated (Boots detected)

    // Training mode - captures photos without inference/deterrent
    bool trainingMode = false;

    // Peripheral states — tracked for BLE status broadcast and test UI
    bool pirActive = false;       // Live PIR sensor reading (P0)
    bool flashLedOn = false;      // Flash LED state (P7)
    bool ledStripOn = false;      // LED strip state (P5+P6)
    bool sprayOn = false;         // Atomiser/spray state (P3)
    unsigned long sprayAutoOffAt = 0;  // millis() time to auto-off spray (0 = no timer)

    // Deterrent settings (persisted to NVS, configurable via MQTT)
    float triggerThresh = 0.80f;  // Boots confidence required to fire deterrent (0-1)
    bool dryRun = false;          // When true, skip atomizer but run all other steps
    bool claudeInfer = false;     // When true, send ?claude=1 to infer Lambda for parallel Claude vision

    // Camera sensor settings
    CameraSettings cameraSettings;
};

#endif

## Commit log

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2025-08-01 Fixes build & adds OTA
    [SystemState.h, main.cpp]
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2025-10-04 A whole bunch of fixes trying (unsuccessfully) to get OTA udpates working
    [main.cpp]
2025-10-05 2-partition OTA now working
    [partitions_custom.csv]
2025-10-09 Bootloader & BluetoothOTA working!
    [partitions_bootloader.csv]
2025-10-11 Fixes log retrieval. Disables auto status updates
    [main.cpp]
2026-01-16 Add ESP32-S3 support (Arduino framework)
    - Add esp32s3cam environment to bootloader and catcam platformio.ini
    - Create 16MB partition tables (partitions_*_s3.csv)
    - Update bootloader with S3 pins, HardwareSerial for UART, SD_MMC.setPins()
    - Update catcam with S3 I2C pins (GPIO 4/5) and board detection
    - Update SDLogger with S3 SD card pin configuration
    - Add CLAUDE.md with build/flash instructions
    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
    [partitions_bootloader_s3.csv, partitions_custom_s3.csv]
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2026-01-18 Minor tidies & fixes, add inference test_script
    [main.cpp]
2026-01-18 Fixes LED flash, adds project directory hints to CLAUDE.md
    [main.cpp]
2026-01-19 Fixes camera frame buffering issue
    [main.cpp]
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2026-01-23 Refactors embedded directory
    [partitions_bootloader.csv, partitions_bootloader_s3.csv, partitions_custom.csv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]
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2026-01-27 Adds some docs images
    [bootboots.fz]
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2026-01-28 Shortens LED flash to camera capture duration only
    [main.cpp]
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2026-02-03 Add internal project support to firmware cleanup Lambda
    - Read `internal` metadata from S3 objects when listing firmware versions
    - Include `internal: true` in manifest.json if any version has the flag
    - Projects with `internal: true` will be filtered from the sandboxsite dropdown
    This enables hiding internal projects like the bootloader from users.
2026-02-03 Remove firmware cleanup Lambda (moved to sandboxsite)
    - Remove FirmwareCleanupStack and Lambda code (moved to sandboxsite)
    - Update bucket name references to nakomis-firmware-updates in docs
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2026-02-04 Add /devices API endpoint and IoT thing attributes
    - Create list-devices Lambda to query IoT things
    - Add GET /devices endpoint to API Gateway with IAM auth
    - Update IoT thing with project attributes via AwsCustomResource
    (project: bootboots, deviceType: bootboots, capabilities)
2026-02-04 Add WebSocket API for MQTT remote control (Increment 2)
    - Create WebSocketApiStack with API Gateway WebSocket API
    - Add DynamoDB table for connection management
    - Create Lambda handlers:
    - connect: stores connection ID
    - disconnect: removes connection
    - sendCommand: publishes to IoT MQTT topic
    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
2026-02-04 Fix CORS for AWS Signature V4 headers
    - Add X-Amz-Date, X-Amz-Security-Token, X-Amz-Content-Sha256 to allowed headers
    - Add GET to allowed methods for /devices endpoint
    - Restrict origins to sandbox.nakomis.com and localhost
2026-02-04 Move /devices endpoint to sandboxsite shared API
    Removed list-devices Lambda and /devices endpoint from bootboots
    API Gateway - this functionality is now in the shared sandbox API
    at api.sandbox.nakomis.com for use by all projects.
    Also reverted CORS headers to remove AWS Sig V4 headers that were
    only needed for the /devices endpoint.
2026-02-04 Remove WebSocket stack from bootboots
    WebSocket API has been moved to sandboxsite shared infrastructure at
    ws.sandbox.nakomis.com to support multi-project device communication.
2026-02-05 Fixes MQTT commands to device
2026-02-06 Adds first draft base for 3d printed case
    [Base.3mf, Base.stl]
2026-02-06 Fixes MQTT initialization, fixes camera status reporting
    [main.cpp]
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2026-02-10 Adds 3d README.jpg
    [bootboots.stl]
2026-02-21 Updates Base & Lid for printing
    [BBBase.3mf, BBBase.stl, BBLid.3mf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]
2026-02-21 Updates fritzing & moves to pcb folder
    [bootboots.fz]
2026-02-21 Fix sagemaker:AddTags IAM permission and update AI training docs
    - Add sagemaker:AddTags to trigger Lambda IAM policy (required when
    CreateTrainingJob includes Tags)
    - Update ai/README.md: current class distribution (incl. old images
    migrated from bootbootstraining), async Lambda invocation, new
    troubleshooting entries, updated Next Steps
    - Update infra/CLAUDE.md: Docker requirement, AI training notes,
    old images migration history
2026-02-21 Add custom training script and wire into CDK as S3 asset
    - infra/training/train.py: MobileNet v2 transfer learning script for
    the SageMaker TF container; reads training/validation channels,
    applies augmentation, early stopping, and saves a versioned SavedModel
    - ai-training-stack.ts: package training/ as a CDK S3 asset on deploy,
    grant SageMaker role read access, pass bucket/key to trigger Lambda
    - ai-training-trigger handler: use asset S3 URI for
    sagemaker_submit_directory; drop unused JumpStart-specific hyperparams
2026-02-21 Skip corrupt JPEG images during data prep and training
    Data prep Lambda now validates each image using S3 range GETs (checks
    FF D8 FF header and FF D9 footer) before copying to the training bucket.
    Corrupt images are skipped and logged rather than failing the job.
    train.py also pre-scans its local input directories and removes any
    corrupt files before building the tf.data pipeline, as a belt-and-
    braces fallback.
    Adds scripts/clean-corrupt-images.py for ad-hoc S3 auditing.
2026-02-21 Patch truncated JPEGs in data prep instead of skipping them
    Old catcam images were captured with a truncated JPEG stream - they have
    a valid FF D8 FF header but are missing the FF D9 end-of-image marker.
    These are now patched on-the-fly during data prep: the Lambda downloads
    the image, appends FF D9, and puts it into the training bucket. Valid
    images continue to use the faster server-side CopyObject.
2026-02-21 Switch to binary Boots/NotBoots classifier
    The real use case is purely binary: spray water at Boots (neighbour's
    cat), don't spray the household cats. A binary classifier focuses all
    model capacity on this one distinction.
    - CAT_CLASSES reduced to ['Boots', 'NotBoots']
    - Data prep Lambda remaps all non-Boots records to NotBoots and caps
    the class at MAX_NOTBOOTS_SAMPLES=600 (~3x Boots count) for balance
    - train.py and training trigger need no changes (parameterised by
    num_classes which now resolves to 2)
    - Docs updated; previous 7-class model preserved at tag multi-cat-recognition
2026-02-21 Infra: binary model, catcam-events table, SMS, events-query endpoint
    - infer-lambda: update CAT_NAMES to ['Boots','NotBoots'] for binary classifier;
    write event record to catcam-events DynamoDB table when Boots confidence >= 0.5
    - video-notification: add SNS direct SMS notification (replaces Pinpoint which
    is unavailable to new AWS customers since May 2025)
    - events-query: new Lambda for GET /events — scans catcam-events with
    minConfidence filter and returns signed S3 image URLs
    - api-gateway: add catcam-events DynamoDB table (GSI on timestamp), events-query
    Lambda + GET /events endpoint, SNS publish permission for SMS
2026-02-21 Firmware: binary model, new deterrent sequence, configurable thresholds
    - DeterrentController: new activate sequence — LED strips on → start video
    → 1s delay → atomizer on (if !dryRun) → 8s → atomizer off → stop video
    → LED strips off → upload video
    - DeterrentController: shouldActivate now accepts triggerThresh parameter
    instead of hardcoded 0.80; removes debug 'return true' bypass
    - VideoProgressCallback: changed from raw function pointer to std::function
    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
2026-02-21 Updates architecture diagram for binary model pipeline
    - Rename SNS node to Notification Lambda (Lambda icon style)
    - Fix dangling edge: Notification Lambda now connects to SMS node
    - Remove spurious edges from Notification Lambda and S3 Video to ESP32
    - Add DynamoDB catcam-events node
    - Add edge from Inference Lambda to DynamoDB catcam-events
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2026-03-26 Update I2C pins to GPIO47/21, fix PCF8574 address, bump version to 1.0.316, disable legacy esp32cam build env
    [main.cpp]
2026-03-26 Add peripheral test controls: set_peripheral BLE command and PIR/LED/spray state in status broadcast
    - Adds pirActive, flashLedOn, ledStripOn, sprayOn fields to SystemState
    - Includes peripherals object in BLE status JSON so web UI reflects live state
    - Registers set_peripheral command handler (flash_led / led_strip / spray)
    - LED strip drives both P5 and P6 channels together
    - Polls PIR sensor each loop iteration and updates systemState.pirActive
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2026-03-26 Fix OTA SSL memory failure by fully deinitialising BLE stack before download
    Stopping BLE advertising only freed ~2KB, leaving the internal heap fragmented
    with a max contiguous block of ~23KB — not enough for the SSL handshake (~40KB).
    btStop() + esp_bt_mem_release(ESP_BT_MODE_BLE) properly shut down the BLE
    controller and release ~50-80KB of internal SRAM. This bypasses the Arduino
    BLE deinit hang (esp32-snippets #1155) by going direct to ESP-IDF.
    The device reboots after every OTA so losing BLE post-shutdown is harmless.
    Applied to both BluetoothOTA (BLE-triggered) and MqttOTA (MQTT-triggered).
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2026-03-26 Split get_settings into get_settings + get_camera_settings to stay under BLE 512-byte GATT limit
    get_settings now returns only basic settings (training_mode, trigger_threshold,
    dry_run, claude_infer) — well under 512 bytes. A new get_camera_settings command
    returns the 26 camera fields (type: camera_settings), also comfortably under limit.
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2026-03-26 Broadcast BLE status every 2s so PIR and peripheral state update live in web app
    updateSystemStatus was defined but never called on a timer, so the web app only
    saw a status snapshot on initial connection. Now SystemManager::update() pushes
    a notification every 2 seconds when a client is connected, keeping pirActive and
    peripheral states live without requiring a manual refresh.
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2026-03-26 Revert "Device version bumped to 1.0.320"
    This reverts commit 771c9a8e511b8525848ad939832c5a1afd5c8063.
2026-03-26 Move PIR sensor from PCF8574 P0 to direct GPIO 42
    MotionDetector now takes a GPIO pin number rather than a PCF8574Manager pointer,
    reads via digitalRead(), and exposes readRawState() for the BLE status poll in
    main.cpp. MotionDetector initialisation in SystemManager is now unconditional
    (no longer gated on PCF8574 readiness). DeterrentController init retains its
    PCF8574/pcf8574Ready guard as it still drives the atomiser via the expander.
    [main.cpp]
2026-03-26 Fix SageMaker ContentType: application/x-image → image/jpeg
    The model endpoint rejects application/x-image with a 415 Unsupported Media Type.
    The firmware already sends image/jpeg; the Lambda was the only mismatched step.
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2026-03-26 Add simulate_detection BLE command for deterrent sequence testing
    Registers a new command that triggers the full deterrent sequence
    (LED strips, 10s video recording, video upload) with a synthetic Boots
    result, bypassing photo capture and SageMaker inference. Respects the
    dryRun flag. Responds with simulation_started before the blocking call
    and simulation_complete when done.
    [main.cpp]
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2026-03-28 Fix atomizer: default off, 5s auto-off on spray command
    - atomizerEnabled now defaults to false so web UI toggle starts in
    correct off state rather than showing on due to stale default
    - set_peripheral spray command now auto-offs after 5 seconds instead
    of staying on indefinitely
    - Added sprayAutoOffAt timer field to SystemState; loop() checks it
    each iteration and turns atomizer off when elapsed
    [SystemState.h, main.cpp]
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2026-03-28 Add pcf8574_ready and peripherals to get_status BLE response
    Peripheral Controls panel in the web app reads pcf8574_ready from the
    status response to enable/disable toggles, and reads the peripherals
    object to sync PIR/LED/spray state after a manual status poll. Neither
    field was being sent, so the controls were always disabled and PIR state
    never reflected the live reading.
    Bump version to 1.0.332.
2026-03-31 Replace TypeScript inference server with Python Flask (serve.py)
    @tensorflow/tfjs-node requires building native C++ bindings which fails on
    macOS arm64. serve.py uses the same Python venv and .keras model as the
    training scripts — no conversion step, no native compilation, no extra deps
    beyond flask and flask-cors.
    API contract unchanged: POST /predict with raw JPEG bytes → { prediction, confidence }.
2026-03-31 Fix Private Network Access header for Chrome HTTPS→localhost requests
2026-03-31 Exclude Multi-labelled images from training data downloads
    Images labelled "Multi" (multiple cats in frame) are skipped by both
    download_data.py and download_data_multiclass.py. They're ambiguous
    training examples and the confidence threshold handles the runtime case.
2026-03-31 Training pipeline improvements: EfficientNetV2B1, pipeline augmentation, LR finder
    - Switch base model from MobileNetV2 to EfficientNetV2B1 (240x240, 79.8% top-1)
    - Move augmentation out of model into Dataset.map() pipeline — fixes SeedGenerator
    serialisation issue and enables async CPU augmentation during GPU training
    - Add RandomContrast + RandomBrightness for variable kitchen lighting
    - Replace RandomZoom with directional zoom-in only (crop-style, min_scale~0.7)
    - Add --find-lr flag: learning rate range test with suggested LR output + plot
    - Add --lr flag to set learning rate explicitly (default 0.0001)
    - Simplify export_for_sagemaker.py: remove two-step workaround, direct save works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
2026-10-11 feat(infra): allow app.sandbox.nakomis.com origin (FLEET-4)
    The BootBoots panel moves into nakomis-shell at app.sandbox.nakomis.com. Allow that origin
    alongside sandbox.nakomis.com on the images bucket CORS (catcam-training reads), the API
    preflight, and the events Lambda (which now echoes allow-listed origins instead of '*').
    Gateway 4xx/5xx responses echo the request Origin so errors stay readable from both sites.
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2026-10-11 fix: address review — stable services, shared credential fetch, socket races (FLEET-4)
    - BootbootsContext keys services on env, user, region and identity pool, and
    reads the shell's token/credential functions through a ref, so a fresh
    ShellContext object doesn't rebuild clients or reopen the WebSocket.
    - Concurrent credential requests share one in-flight fetch; refresh only
    once it has settled and is within the margin.
    - LiveUpdates: a generation counter stops a stale connect() opening a
    second socket after stop()/start(); stop() no longer schedules a reconnect.
    - BLE: listen for disconnects before setup and disconnect GATT on any setup
    failure.
    - Labelling/bounding shortcuts ign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
2026-10-29 fix(web): read live status over Bluetooth with get_status (BOOT-7)
    The Bluetooth page read the BLE status characteristic, which firmware
    1.0.331 only sets at boot, and never asked for status after connecting.
    After a refresh the peripheral toggles showed off while the LEDs were on.
    requestStatus now always sends get_status, which the firmware answers
    from live SystemState, and the Bluetooth page requests it on connect.
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2026-10-29 feat(catcam): read Thing, Wi-Fi, endpoints and credentials from a prov partition (BOOT-10)
    Carve a 64 KB 'prov' NVS partition from the front of the unused spiffs
    partition (0x810000) and read the device's identity, Wi-Fi, IoT and
    credentials-provider endpoints, API host, root CA, certificate and key
    from it at boot. Without it the device logs NOT PROVISIONED, skips
    Wi-Fi/AWS/MQTT and still starts BLE. secrets.h and its generator go:
    the image no longer needs them and holds no secrets or environment.
2026-10-29 feat(catcam): set the firmware version at build time (BOOT-10)
    extra_script.py passes -DFIRMWARE_VERSION from the FIRMWARE_VERSION
    environment variable (default 0.0.0-dev); version.h is no longer
    hand-bumped. A 'bootboots-version:<v>' tag, printed at boot, lets
    image-checks match an image to its version (the app descriptor's
    version is the Arduino lib-builder's, not ours).
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2026-10-29 feat(catcam): provision, image-check and publish scripts (BOOT-10)
    provision.sh builds the prov NVS image from SSM, IoT and the root CA in
    a private temp directory, checks it with ESP-IDF's NVS parser, checks
    the device's partition table has prov, and writes it with
    --after watchdog_reset (or stops at --image-only OUT).
    image-checks.sh fails an image without the expected version tag, with a
    PEM block, a per-device/per-environment string, or the Wi-Fi SSID or
    password (fetched from SSM at check time, never echoed).
    publish-firmware.sh runs the checks and uploads
    BootBoots/<version>/firmware.bin with its sha256, never replacing a
    published version (--if-none-match '*'); --dry-run writes noth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
2026-10-29 fix(infra): retain the images bucket and catcam-events table (BOOT-8)
    Both were RemovalPolicy.DESTROY (the bucket with autoDeleteObjects), so deleting or replacing the
    API stack would have taken the cat photos with it. CDK's auto-delete handler (the deployed one too)
    only empties a bucket still tagged aws-cdk:auto-delete-objects=true, and the bucket update drops the
    tag before the custom resource is deleted, so turning it off doesn't empty the bucket. The only
    bucket-policy statement removed is the auto-delete role's own grant.
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2026-10-29 docs: one repo — root README/CLAUDE.md, infra and embedded docs (BOOT-8)
    - Root README and CLAUDE.md describe embedded/, infra/, web/ and docs/, the environments and the
    deploy rules; sandboxsite is gone.
    - infra/CLAUDE.md: pnpm, NPM_ENVIRONMENT, the five stacks, scripts, CI placeholder context, data
    retention and where the backup is.
    - embedded/CLAUDE.md: Fleet OTA and nakomis-firmware-sandbox instead of localhost:3000 and the
    deleted nakomis-firmware-updates bucket; catcam_logs.py.
    - web/CLAUDE.md and infra/README.md no longer say 'cdk deploy --all', which in the single app would
    delete the SageMaker endpoint.
2026-10-29 feat(infra): CDK owns the SageMaker endpoint via model.json (BOOT-9)
    - infra/model.json names, per environment, the artefact in that environment's bootboots-models
    bucket and a label (null: no endpoint; sandbox must always have one). Set to the live model,
    local-models/20260331T203825.
    - The model and endpoint config are named bootboots-<label> / bootboots-config-<label>, so a new
    model creates a new pair and the endpoint switches in place. They match what deploy_model.sh made
    by hand (TF Serving 2.16, no container environment, no role on the config, serverless 2048 MB / 5).
    The endpoint is retained if the stack or the model entry goes.
    - No more modelDataUrl context: deploy-sandbo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
2026-10-29 fix(catcam): pin provisioning tools, stricter prov and publish checks (BOOT-10)
    - requirements-provision.txt pins esp-idf-nvs-partition-gen and esptool;
    provision.sh honours NVS_GEN_PYTHON (and fails if it can't import the
    generator) and takes esptool from that Python when it has it.
    - prov_image.py verifies the NVS image itself (page/entry/data CRCs, a
    free page, every key) and the device's partition table, with only the
    standard library; ESP-IDF's integrity check still runs when available
    and fails on an exception or a reported problem.
    - publish-firmware.sh only treats a 404 from head-object as "not
    published"; AccessDenied, a bad profile or a network error stop it.
    - image-ch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
